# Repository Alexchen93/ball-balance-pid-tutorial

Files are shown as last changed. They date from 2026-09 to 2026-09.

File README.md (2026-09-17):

# Arduino Nano 電腦視覺球平衡控制

這是一套給學生學習「影像辨識、座標轉換、回授控制與 PID」的球平衡平台。Desktop 的 USB 攝影機辨識球的位置，Python 將平台座標傳給 Arduino Nano；Nano 依座標控制兩顆 Servo，讓球回到平台中心。

> **安全第一：** Servo 必須使用獨立、足夠電流的 5–6 V 電源，外部電源 GND 必須與 Nano GND 共地。不要使用 Nano 的 5 V 腳供應 Servo。第一次測試請空載、小角度，並隨時可斷開 Servo 電源。

## 系統架構

```text
USB 攝影機 → OpenCV：球色辨識、接觸點估計、透視校正
                                  ↓ POS / LOST / GEOM / RUN
Desktop ───────────────────── USB Serial ─────────────────→ Arduino Nano
                                                               ↓
                                                     雙軸 PD / 安全限幅
                                                               ↓
                                                       D9、D10 Servo → 平台
```

## 專案內容

| 路徑 | 用途 |
| --- | --- |
| `Camera_Vision/` | Desktop 的 OpenCV 程式、設定與學生操作說明。 |
| `Arduino_Nano_Ball_Balance/` | 正式 Camera PID 韌體與接線／調參說明。 |
| `Arduino_Nano_Ball_Balance_Joystick_Modes/` | **機構校正用**搖桿韌體；不是正式 Camera PID 韌體。 |
| `3d列印檔案/` | 平台、Servo 固定座、鏡頭座等模型（依 `.gitignore` 不上傳）。 |

## 學生先懂這三件事

### 1. 影像像素座標不等於平台控制座標

相機原始影像中：向右是像素 `x` 增加、向下是像素 `y` 增加。因為鏡頭斜拍，平台在畫面裡是梯形；不能直接把像素座標拿去控制 Servo。

按 `C` 依序點 **TL → TR → BR → BL** 後，程式建立 homography（透視校正），把梯形平台轉為正方形控制座標：

| 平台控制座標 | 畫面中的方向 |
| --- | --- |
| `X` 負 → 正 | 左 → 右 |
| `Y` 正 | 平台上方／遠端：TL、TR 的方向 |
| `Y` 負 | 平台下方／近端：BL、BR 的方向 |
| `(0, 0)` | 由四角算出的平台幾何中心 |

所以「影像左右」是 **X 軸**；影像原始向下雖是 `y` 增加，但本專案的控制 `Y` 軸刻意翻轉，讓上方為正、下方為負。

### 2. 綠色圓與橘色 CONTACT 點不同

- **綠色圓**：HSV 找到的球外框與其影像圓心。
- **橘色 `CONTACT` 點**：估計球接觸平台的位置，才是送給 Nano 控制與判斷是否在平台內的點。

斜拍時，球的影像圓心不在平台平面上。程式會依球半徑、平台近端方向，將圓心往接觸方向補償 `0.85 × 半徑`，再做透視轉換。因此請確認**橘色點**而非綠色圓心落在球接觸平台的位置附近。

### 3. PID 在 Nano，不在 Desktop

Camera Vision 只傳送球的位置與安全狀態；正式 Nano 韌體才是 PID、Servo 方向與安全角度的唯一來源。目前起始參數是保守 PD：

```text
X/Y：Kp = 1.25、Ki = 0.00、Kd = 0.12
```

- `P`：球偏離中心越遠，回拉傾斜越大。
- `D`：球快速往外滾時，提早加強煞車。
- `I`：目前保持 0，避免積分造成過衝。

詳見 `Arduino_Nano_Ball_Balance/README.md`。

## 第一次使用流程

### 1. 校正機構並燒錄正式 Nano 韌體

1. 在 Arduino IDE 安裝 `Servo` 函式庫。
2. 先用 `Arduino_Nano_Ball_Balance_Joystick_Modes/` 校正平台水平、Servo 中心與安全端點。
3. 把 `SETC` / `SHOW` 的結果填入正式 `Arduino_Nano_Ball_Balance/Arduino_Nano_Ball_Balance.ino` 的中心與限幅常數。
4. 選擇 **Arduino Nano**（舊板上傳失敗時試 `ATmega328P (Old Bootloader)`），燒錄正式 `.ino`。
5. 使用 Camera Vision 前關閉 Arduino Serial Monitor；它會佔用 Nano 的 serial port。

### 2. 在 Desktop 安裝 Camera Vision

```bash
cd ~/文件/平衡球PID教案/Camera_Vision
python3 -m venv .venv
.venv/bin/python -m pip install --upgrade pip
.venv/bin/python -m pip install -r requirements.txt
```

若顯示 Nano 沒有讀寫權限，將目前 Desktop 使用者加入 serial 群組，登出再登入並重新插拔 Nano：

```bash
sudo usermod -aG dialout "$USER"
```

### 3. 固定鏡頭並完成 B、C

1. 鏡頭固定後，讓四角和整個平台都入鏡；鏡頭或平台移動後一定要重新按 `C`。
2. 執行 `./start_camera_vision.sh`。
3. 選 `2` 可先只測鏡頭，選 `1` 會連接可用 Nano。
4. 按 `B`，點球中心取樣 HSV。綠色圓應穩定包住球。
5. 按 `C`，依序點 TL、TR、BR、BL 四角。成功後，橘色 CONTACT 點用來確認接觸位置。
6. 連上 Nano、球在平台內可辨識時，按 `R` 進 RUN；按 `P` 回 READY，按 `Q` / `Esc` 安全離開。

> 此版本已移除 `D` 零點操作：完成 `C` 時，四角計算出的平台中心自動成為 `(0,0)`。

## PID 學習與測試順序

1. 先空載確認兩軸中心、方向與安全限幅。
2. 放球在中心，單軸小幅偏移測試；若球被推得更遠，立刻按 `P`，再調整對應 `SERVO_X_DIRECTION` 或 `SERVO_Y_DIRECTION`。
3. 若球接近邊緣才來得及回拉，先看 telemetry 的 `tilt`：
   - 已接近 ±20°：機構回拉力／Servo 速度或影像延遲可能不足。
   - 尚未接近最大：可小幅提高 `Kp`，或調整 `Kd` 讓高速外移提早煞車。
4. 若出現高頻抖動，先將 `Kd` 由 `0.12` 降為 `0.08`；不要先增加 `Ki`。

## 文件索引

- [Camera Vision 操作與故障排除](Camera_Vision/README.md)
- [Nano 韌體、接線、PD 參數與 telemetry](Arduino_Nano_Ball_Balance/README.md)
- [搖桿機構校正說明](Arduino_Nano_Ball_Balance_Joystick_Modes/README_Joystick_Discrete_Modes.md)

## 授權

本專案採用 [MIT License](LICENSE)。硬體、Servo 電源與機械結構具有風險；使用者應自行完成安全檢查與測試。

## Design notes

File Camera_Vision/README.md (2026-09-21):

# Camera Vision：Desktop 影像辨識與 Nano 通訊

`ball_vision.py` 在 Desktop 取得 USB 攝影機畫面，以 HSV 追蹤球，將平台座標送到 Arduino Nano。Nano 才負責 PID、Servo 方向、限幅與失聯保護。

## Desktop 一次性設定

```bash
cd ~/文件/平衡球PID教案/Camera_Vision
python3 -m venv .venv
.venv/bin/python -m pip install --upgrade pip
.venv/bin/python -m pip install -r requirements.txt
```

Nano 使用 USB serial。確認裝置與權限：

```bash
python3 -m serial.tools.list_ports -v
ls -l /dev/ttyUSB* /dev/ttyACM* 2>/dev/null
```

常見裝置是 `/dev/ttyUSB0` 或 `/dev/ttyACM0`。若顯示目前使用者無法讀寫，執行下列命令後**登出再登入**，並重新插拔 Nano：

```bash
sudo usermod -aG dialout "$USER"
```

Arduino IDE Serial Monitor、其他 serial monitor 或另一個 Camera Vision 視窗都可能佔用 port；啟動前要關閉它們。

## 啟動方式

```bash
cd ~/文件/平衡球PID教案/Camera_Vision
./start_camera_vision.sh
```

啟動後第一步會顯示攝影機**編號選單**。啟動器會先測試並只列出實際能讀取影像的節點，避免選到 USB 攝影機的中繼資料節點。直接選擇內建或外接 USB 鏡頭的編號即可；不需要輸入 `/dev/video*` 路徑、鏡頭 index 或其他攝影機參數。其後的 READY／RUN、HSV 與平台校正操作均與原本相同。

啟動選單：

| 選項 | 用途 |
| --- | --- |
| `1` | 搜尋一個可讀寫、未被占用的 Nano，連線後進 READY。 |
| `2` | 以 `--no-serial` 只檢查鏡頭與校正；不能 RUN。 |
| `q` | 離開。 |

手動指定 serial port：

```bash
.venv/bin/python ball_vision.py --serial-port /dev/ttyUSB0
```

## 座標與畫面標記

### 相機像素與平台座標

相機像素：右方 `x` 增加、下方 `y` 增加。平台控制座標由 `C` 四角透視校正後產生：

| 控制座標 | 對應畫面方向 |
| --- | --- |
| `X-` / `X+` | 左 / 右 |
| `Y+` | TL、TR 的上方／遠端 |
| `Y-` | BL、BR 的下方／近端 |
| `(0,0)` | 四角算出的平台中心 |

請使用校正後的平台座標判讀，不要直接以斜拍畫面的梯形或像素 `y` 判斷方向。

### 球的位置

- **綠色圓**：HSV 偵測到的球外框；紅點是影像圓心。
- **橘色 `CONTACT` 點**：推估的球與平台接觸點；程式實際傳送給 Nano、檢查是否在邊框內的就是這個點。

球有高度，斜拍時綠色圓心不在平台平面。程式以 `camera_config.json` 的 `detection.contact_offset_radius`（目前 `0.85`）乘球半徑，朝 TL/TR 到 BR/BL 的近端方向補償。如果橘點長期在接觸點上方或下方，再小幅調整此值；不要直接以綠色圓心取代它。

## READY → RUN 操作

| 操作 | 功能 |
| --- | --- |
| `a` | 重新讀取已儲存的 `camera_config.json`。 |
| `b` | 點球中心，取樣 HSV。 |
| `c` | 點 TL → TR → BR → BL 四角；完成後自動把幾何中心設為零點。 |
| `n` | 重新搜尋 Nano。 |
| `p` | 回 READY；停止 live `POS` / `LOST` / Servo 控制。 |
| `r` | Nano 已連線、球可辨識、B/C 完成時進 RUN；RUN 中再按一次回 READY。 |
| `q` / `Esc` | 安全停止並離開。 |
| `Ctrl+C`、停止 `.sh` 程序或 `SIGTERM` | 安全關閉影像視窗、釋放攝影機，並送 Nano 回 `READY`。 |

> 沒有 `D` 操作。C 成功後，平台中心自動是 `(0,0)`。

### 校正順序

1. 固定鏡頭與平台，四角完整入鏡。
2. 按 `B` 點球中心；確認綠色圓穩定包住球。
3. 按 `C`，依序點 TL、TR、BR、BL。錯誤順序、重複、內凹或退化四邊形會被拒絕，上一份有效設定會保留。
4. 確認橘色 CONTACT 點靠近球接觸平台的位置。
5. 連接 Nano，讓球留在平台內，再按 `R`。

`C` 成功後會寫入 `camera_config.json`。鏡頭、平台或解析度改變後必須重新做 `C`。

## 安全與故障排除

- READY 中不會送 `POS`、`LOST` 或 Servo 控制；按 `P` 可隨時回 READY。
- Nano 連續約 300 ms 沒收到新位置或收到 `LOST`，會回中立角。
- `Cannot RUN: Nano is not connected`：按 `n` 搜尋，檢查 USB、權限與 Serial Monitor。
- `Cannot RUN: HSV candidate is outside...`：目前辨識到的候選接觸點不在 C 的平台內。重新做 B / C，或檢查橘色 CONTACT 點補償。
- `ERROR,POSITION_OUT_OF_RANGE`：Nano 拒絕範圍外的位置；確認使用最新版 Camera Vision，並檢查 B、C 和橘色 CONTACT 點。
- 若球被推向更遠方向，立即按 `P`，再調整 Nano 的 `SERVO_X_DIRECTION` 或 `SERVO_Y_DIRECTION`；Camera Vision 不設定 PID。

## 通訊摘要

RUN 前的安全握手：

```text
GEOM,-100,100,-100,100 → GEOM,OK
fresh POS                → POS,OK
final fresh POS + RUN    → STATE,RUN
```

RUN 中，Desktop 傳送 `POS,x_pct,y_pct,timestamp_ms`；找不到球才傳 `LOST`。Nano 韌體不接受 Camera Vision 下發 PID 參數，`PIDX` / `PIDY` 會回 `ERROR,PID_MANAGED_BY_NANO`。

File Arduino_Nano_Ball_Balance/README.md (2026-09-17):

# Arduino Nano：正式 Camera PID 韌體

這個資料夾是正式控制韌體。Desktop 的 `Camera_Vision/ball_vision.py` 只傳送平台座標與安全狀態；Nano 是 PID、Servo 方向、限幅與失聯保護的唯一控制權威。

> `Arduino_Nano_Ball_Balance_Joystick_Modes/` 是校正韌體，不是正式 Camera PID 燒錄目標。

## 接線與安全

| Nano 腳位 | 用途 |
| --- | --- |
| D9 | Servo X 訊號 |
| D10 | Servo Y 訊號 |
| USB | Desktop Serial（115200 baud）與燒錄 |
| GND | 與 Servo 外部電源 GND 共地 |

兩顆 Servo 必須使用獨立、足夠電流的 5–6 V 電源；不得由 Nano 的 5 V 腳供應。

## 燒錄與機構校正

1. Arduino IDE 安裝 `Servo` 函式庫。
2. 先使用搖桿校正韌體找平台水平、Servo 中心與安全端點。
3. 將 `SETC` / `SHOW` 結果填入 `.ino` 頂端的：
   - `SERVO_X_CENTER`
   - `SERVO_Y_CENTER`
   - `SERVO_LIMIT_OFFSET_DEG`
4. 選擇 Arduino Nano 後燒錄；舊 Nano 上傳失敗時選 `ATmega328P (Old Bootloader)`。
5. 先以小角度測試方向。球被推得更遠時，立即停止，修改相對應 `SERVO_X_DIRECTION` 或 `SERVO_Y_DIRECTION` 後重燒。

Arduino Serial Monitor 會佔用 USB serial；使用 Camera Vision 前務必關閉它。

## 控制座標與通訊

Camera Vision 的 `C` 四角將平台映射為百分比座標：

- 左 → 右：`X-` → `X+`
- 平台上方／遠端 TL、TR：`Y+`
- 平台下方／近端 BL、BR：`Y-`
- 平台中心：`(0,0)`

Nano 接收：

```text
GEOM,-100.00,100.00,-100.00,100.00
POS,12.4,-8.7,12345
LOST
RUN
READY
```

安全握手為：

```text
GEOM → GEOM,OK → fresh POS → POS,OK → final fresh POS + RUN → STATE,RUN
```

位置範圍由 `GEOM` 提供。Nano 只接受有界、有限且新鮮的 `POS`；超出範圍會回 `ERROR,POSITION_OUT_OF_RANGE`，找不到球或資料逾時會停止控制並回中立。

Telemetry 每秒約 10 次：

```text
TEL,state,link,x_pct,y_pct,e_x_pct,e_y_pct,u_x_pct,u_y_pct,tilt_x_deg,tilt_y_deg,servo_x,servo_y,age_ms
```

學生觀察邊緣回拉時，特別看：

- `ball`：球的位置。
- `error`：目標中心與球的正規化誤差。
- `output`：PID 輸出百分比。
- `tilt`：要求的平台傾斜角。
- `servo`：實際寫出的 Servo 角度。

若球接近邊緣但 `tilt` 已接近 ±20°，代表可能是 Servo／機構回拉力或影像延遲，而不只是 PID 參數。

## 目前 PD 起始參數

```cpp
DEFAULT_KP_X = 1.25f;
DEFAULT_KI_X = 0.00f;
DEFAULT_KD_X = 0.12f;
DEFAULT_KP_Y = 1.25f;
DEFAULT_KI_Y = 0.00f;
DEFAULT_KD_Y = 0.12f;
```

公式：

```text
error = target - ball
u = Kp × error + Ki × integral(error) + Kd × derivative(error)
tilt = clamp(u, -1, +1) × 20°
```

- `Kp` 提高可讓球還未到邊緣時更早回拉。
- `Kd` 在球快速外移時提供提早煞車；過大會放大影像雜訊、造成抖動。
- `Ki` 現在為 0，因為它無法煞住移動中的球，且容易造成過衝。

若高頻抖動，先將 `Kd` 從 `0.12` 降到 `0.08`；若回拉太慢且沒有明顯抖動，再小幅提高 `Kp`。每次只改一組小幅數值、重新燒錄並記錄結果。不要把 Servo 安全端點當成 PID 調參工具。

## Camera Vision 的責任邊界

Camera Vision 負責 HSV、平台四角與球接觸點估計。它不保存或下發 PID；`PIDX` / `PIDY` 命令會被 Nano 拒絕為 `ERROR,PID_MANAGED_BY_NANO`。任何 PID、Servo 中心、方向或安全端點變更，都必須修改此 `.ino` 後重新燒錄。

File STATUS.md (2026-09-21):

# 平衡球 PID 平台目前狀態

更新日期：2026-09-15

## 已完成且已做程式層驗證

- 正式控制流程由 Nano 韌體掌管 PID；Camera Vision 只在 RUN 前傳送平台幾何資訊與即時位置。
- RUN 握手固定為：`GEOM` → `GEOM,OK` → fresh `POS` → `POS,OK` → final fresh `POS` + `RUN` → `STATE,RUN`。
- 平台範圍由每次四角校正（C）與零點（D）推導，可處理不對稱的零點與平台邊界；Nano 依近、遠邊距離分別正規化 PID 誤差。
- Servo X/Y 各自使用安全中心與安全端點；目前程式中的中心為 X=74°、Y=76°，安全行程為各軸中心 ±20°。

## 2026-09-15 RUN 握手修正

### 問題

Nano 已正確回覆 `GEOM,OK`，但 Python 的 `NanoTransport.poll()` 只把 `ERROR`、`STATE`、`POS,OK` 交給 RUN 狀態機。`GEOM,OK` 因此只顯示在終端，沒有推進 `wait_geom_ack`，造成 RUN 逾時並回到 READY。

### 修正

- `Camera_Vision/ball_vision.py` 現在將 `GEOM,OK` 納入已解析事件。
- `Camera_Vision/tests/test_nano_transport_serial.py` 新增 `GEOM,OK` 回歸測試，防止同類 ACK 再次被僅列印、不交給狀態機。

### 驗證

在 `Camera_Vision/.venv` 執行全部單元測試：**19 tests passed**。

## 尚待實機確認

- 需要重新啟動 Camera Vision，使用已燒錄目前 `Arduino_Nano_Ball_Balance.ino` 的 Nano 做一次受控 RUN 測試。
- 測試前關閉 Arduino Serial Monitor，使用 A 套用已存設定，確認球置於中心；按 R 後預期會看到 `GEOM,OK`、`POS,OK`、`STATE,RUN` 與 `RUN confirmed`。
- 若位置、相機或機構調整，重新執行 C（TL → TR → BR → BL）與 D（零點）後再 RUN。

## 2026-09-21 鏡頭選擇與安全關閉

### 調整

- `Camera_Vision/start_camera_vision.sh` 在既有 Nano 啟動選單前加入攝影機編號選擇；學生不需輸入 `/dev/video*` 路徑或 index。
- 啟動器會先以 OpenCV 讀取一張畫面，只列出可實際擷取影像的節點，略過同一支 UVC 攝影機可能出現的 metadata-only `/dev/video*` 節點。
- 原本 `Camera_Vision/ball_vision.py` 的 HSV 偵測、校正、READY/RUN、Nano 通訊與 PID 分工未改變；只加入 SIGINT/SIGTERM 的收尾處理。
- 按 `q`／`Esc`、`Ctrl+C` 或正常停止 `start_camera_vision.sh` 時，程式會關閉 OpenCV 視窗、釋放攝影機並送 Nano 回 `READY`。`kill -9` 無法進行收尾。

### 2026-09-21 驗證

- `python3 -m py_compile Camera_Vision/ball_vision.py`
- `bash -n Camera_Vision/start_camera_vision.sh`
- 以實際內建鏡頭執行 headless 程式後送出 `SIGTERM`：已確認正常結束且 `/dev/video0` 未殘留占用。
- 在 `Camera_Vision/.venv` 執行 27 個 Python 單元測試與 3 個啟動器／韌體靜態測試，全部通過。

### 實機狀態

- Desktop 的 Logitech C922 曾被偵測到，但在本次最後檢查前已從 USB 斷線；重新接上後，僅在可讀取影像時才會出現在選單中。

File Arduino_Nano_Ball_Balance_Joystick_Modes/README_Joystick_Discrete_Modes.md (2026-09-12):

# Arduino Nano 球平衡平台：搖桿離散硬體校正模式

此版本在原本 Camera/OpenCV/PID 流程外，提供 5-pin 雙軸搖桿的安全機構校正模式。完整專案操作請見根目錄 [`README.md`](../README.md)。

## 接線

| Nano | 搖桿 | 功能 |
| --- | --- | --- |
| A0 | VRx | X 軸類比輸入 |
| A1 | VRy | Y 軸類比輸入 |
| D2 | SW | 按鈕，使用 `INPUT_PULLUP` |
| 5V | VCC / +5V | 搖桿供電 |
| GND | GND | 共地 |

Servo X 使用 D9、Servo Y 使用 D10。Servo 仍須由獨立 5–6 V 電源供應，並與 Nano 共地。

## 開機與 TEST 模式

目前版本會在開機後**自動進入 TEST 模式**，不需要先長按搖桿按鈕。進入後預設為 MODE1。

每一次推桿只接受一個軸的一次動作：

- 搖桿必須回到中立區才會重新 armed。
- 動作間至少保留約 350 ms 的安全間隔。
- 斜推時只接受偏移較大的那個軸，因此不會同時改動 X、Y。
- 持續把搖桿推在同一方向不會連續累加。

## Mode 與按鈕操作

| Mode | 每次搖桿動作 |
| --- | --- |
| MODE1 | 選定軸 ±1° |
| MODE2 | 正方向前往推導後的 MAX；負方向前往推導後的 MIN（目前中心 90、範圍 ±20，為 110° / 70°） |

- **短按 SW**：在 MODE1 / MODE2 之間切換。
- **在 TEST 長按 SW 1.5 秒**：X、Y 回到 `testCenterX` / `testCenterY`。

預設中心是 90°，`SERVO_LIMIT_OFFSET_DEG` 是 20，因此端點由 X 中心 ±20 推導為 70°～110°；調整 offset 可改安全行程，不需要手算端點。

## 建議校正流程

1. 平台空載，確認 Servo 有獨立供電與共地。
2. MODE1 以 1° 單步找平台水平。
3. MODE2 逐一測試 X+/X-/Y+/Y-，確認目前由中心 90、範圍 ±20 推導出的 70°～110° 端點不會卡住；若有風險，縮小 `SERVO_LIMIT_OFFSET_DEG`。
4. 在 115200 baud、Newline 的 Serial Monitor 輸入 `SETC`，再輸入 `SHOW`。
5. 將 `SHOW` 印出的 `SERVO_X_CENTER` / `SERVO_Y_CENTER` / `SERVO_LIMIT_OFFSET_DEG` 寫回 `.ino` 頂端的常數並重新燒錄，才會永久保存。
6. 完成機構校正後，才進行攝影機校正與 PID 控制。

## 常用 Serial 指令

- `STATUS`：顯示 Servo、中心、mode 與 armed 狀態。
- `SHOW`：印出可複製回程式的校正常數。
- `SETC` / `SETCX` / `SETCY`：設定測試中心。
- `CENTER`：回到測試中心。
- `MODE,1` / `MODE,2`：選擇 1° 微調或端點模式。
- `STEP,1`：選擇 1° 微調。
- `X+`、`X-`、`Y+`、`Y-`：手動移動指定軸。
- `X,角度`、`Y,角度`、`XY,X角度,Y角度`：直接指定安全範圍內的角度。
- `JOY`：讀取搖桿 ADC 值；`JOYCAL`：重新校正搖桿中立值。
- `TESTX`、`TESTY`、`TESTBOTH`：執行內建來回機構測試。

## 可調參數

```cpp
constexpr int JOYSTICK_DEADZONE = 100;
constexpr uint16_t JOYSTICK_ACTION_DELAY_MS = 350;
constexpr uint16_t JOYSTICK_LONG_PRESS_MS = 1500;
```

若中立時會誤觸發，增加 `JOYSTICK_DEADZONE`；若每次操作要更慢，增加 `JOYSTICK_ACTION_DELAY_MS`。

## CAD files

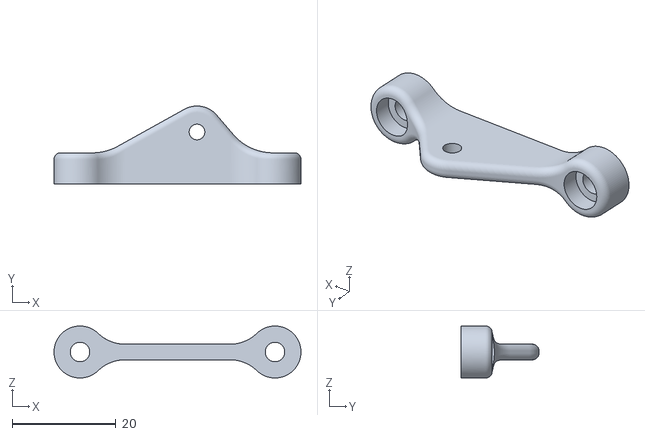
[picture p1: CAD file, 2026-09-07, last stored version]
3d列印檔案/Control Horn v4.stl
47.5 x 15.0 x 10.00

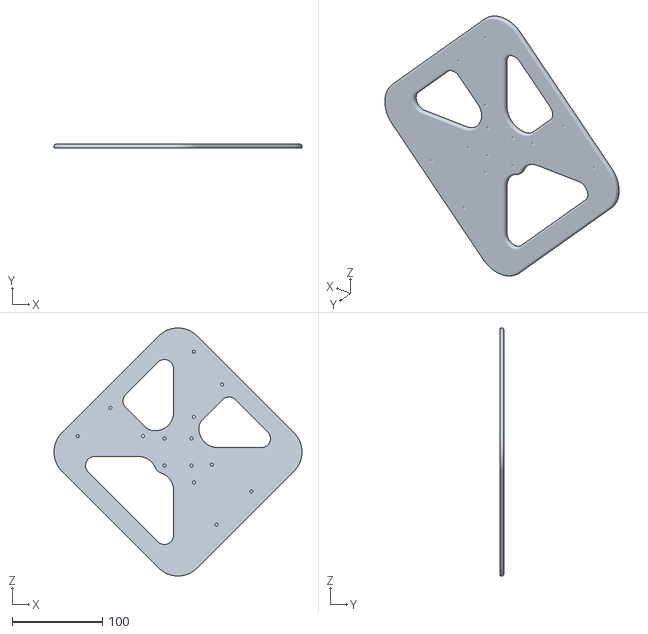
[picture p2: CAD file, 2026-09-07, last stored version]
3d列印檔案/Base v17.stl
275.1 x 4.00 x 275.1

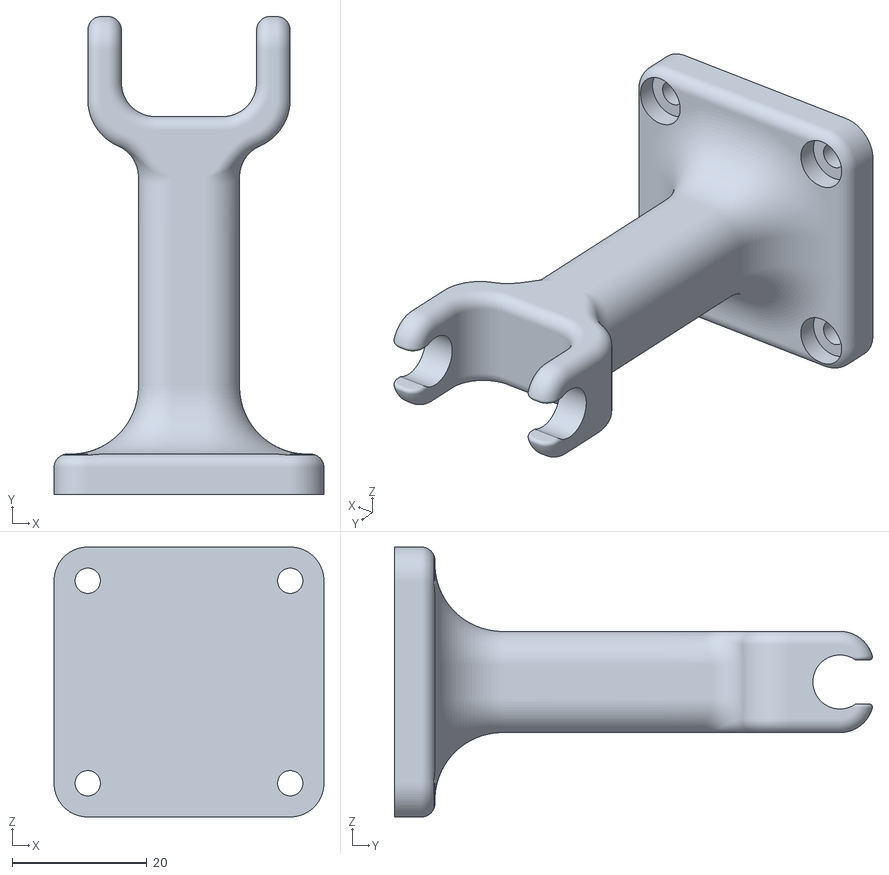
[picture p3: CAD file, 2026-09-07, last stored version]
3d列印檔案/Pivot Post v5.stl
40.0 x 70.8 x 40.0

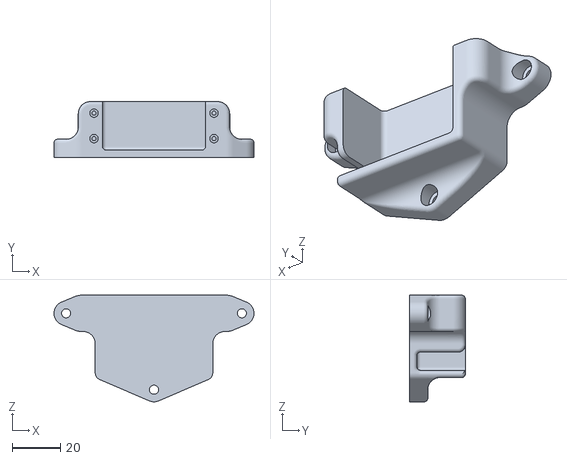
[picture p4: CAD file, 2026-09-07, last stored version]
3d列印檔案/Servo Holder v10.stl
82.5 x 23.0 x 44.0

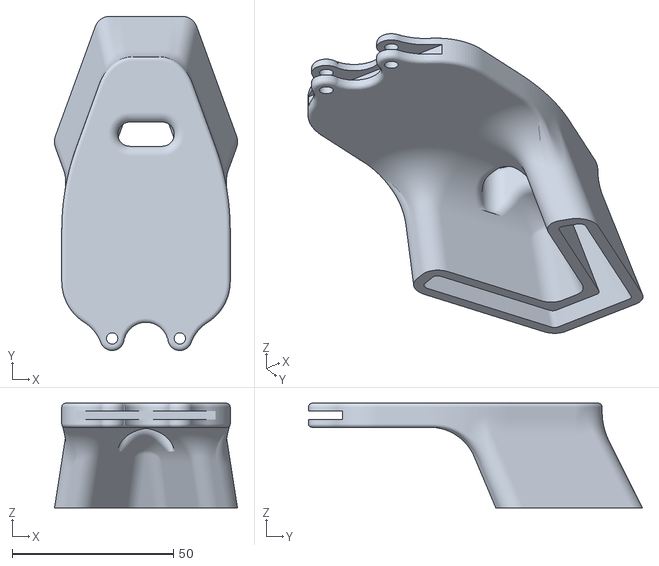
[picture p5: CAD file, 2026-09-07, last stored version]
3d列印檔案/PixyCam Holder v3.stl
56.8 x 103.6 x 32.5

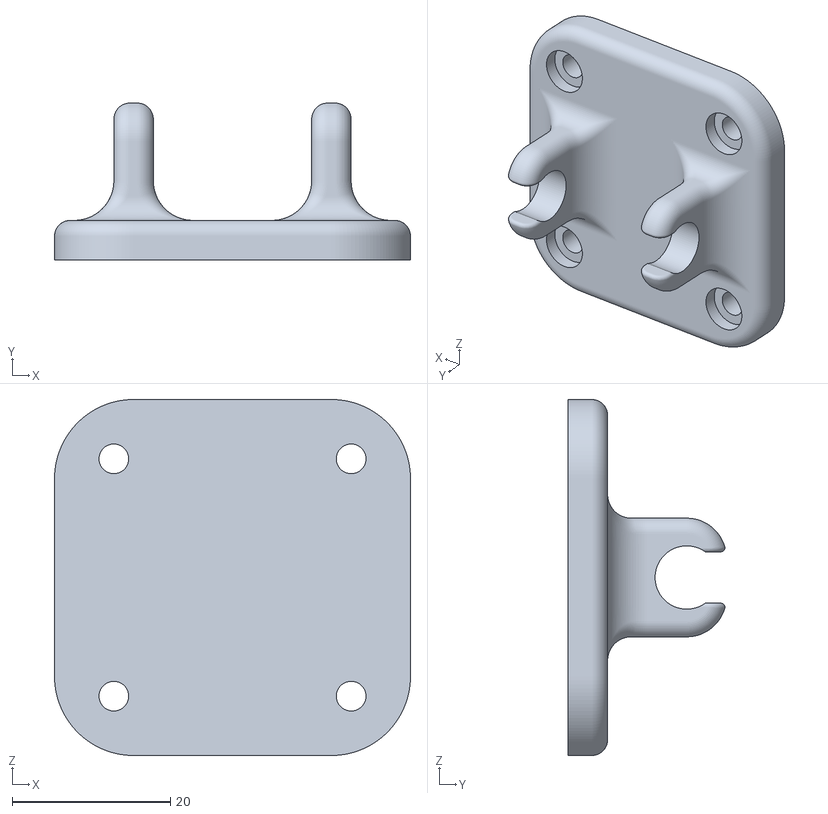
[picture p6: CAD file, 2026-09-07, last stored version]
3d列印檔案/Pivot Pad v5.stl
45.0 x 19.8 x 45.0

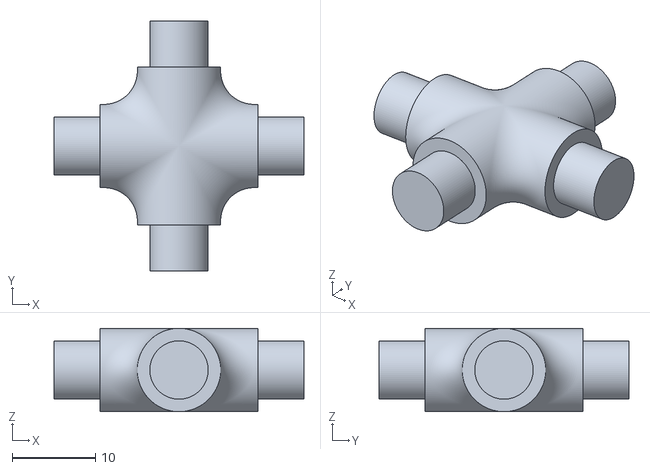
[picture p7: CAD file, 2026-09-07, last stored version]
3d列印檔案/Pivot Cross v3.stl
30.0 x 30.0 x 10.0

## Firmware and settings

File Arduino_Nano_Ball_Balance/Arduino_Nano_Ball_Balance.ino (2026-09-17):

/*
 * Ball-and-Plate controller: PC camera -> USB serial -> Arduino Nano PID
 *
 * PC-to-Nano protocol (ASCII, one command per LF-terminated line):
 *   GEOM,<x_min_pct>,<x_max_pct>,<y_min_pct>,<y_max_pct>
 *   POS,<x_pct>,<y_pct>,<camera_timestamp_ms>
 *   LOST
 *   RUN | READY | TARGET,<x_pct>,<y_pct>
 *   PING | HELP
 *
 * Nano firmware is the only PID parameter source/control authority.
 * PIDX/PIDY commands are rejected with ERROR,PID_MANAGED_BY_NANO.
 *
 * POS replies with POS,OK after the Nano accepts a fresh in-range sample.
 * RUN must be immediately preceded by a fresh accepted POS; READY stops PID and returns servos to neutral.
 * Nano telemetry (10 Hz):
 *   TEL,<state>,<link>,<x_pct>,<y_pct>,<e_x_pct>,<e_y_pct>,<u_x_pct>,<u_y_pct>,<tilt_x_deg>,<tilt_y_deg>,<servo_x>,<servo_y>,<age_ms>
 *
 * Libraries to install from Arduino Library Manager:
 *   Servo
 */

#include <Servo.h>
#include <math.h>
#include <stdlib.h>
#include <string.h>

constexpr uint8_t SERVO_X_PIN = 9;
constexpr uint8_t SERVO_Y_PIN = 10;
constexpr uint8_t STATUS_LED_PIN = LED_BUILTIN;
// ===== 學生校正參數（校正完成後只修改本區） =====
// 來源：校正程式的 SETC / SHOW 結果與學習單紀錄。
// 注意：本次 JOYMOVE / TESTSTAT 觀測到 X=71、Y=76，只代表測試當下的輸出角度，
// 不可當作正式 PID 的機構中心值。正式 PID 請只轉填/調整下列中心與安全行程常數。
// 安全限制：中心應落在各軸 MIN/MAX 之間，端點不可超出校正安全範圍。
// X 軸機構中心角度。校正完成後，從 SETC / SHOW / 學習單轉填；本教案最終中心採 90 度。
constexpr int SERVO_X_CENTER = 74;
// Y 軸機構中心角度。校正完成後，從 SETC / SHOW / 學習單轉填；本教案最終中心採 90 度。
constexpr int SERVO_Y_CENTER = 76;
// Servo 實體安全行程，也是 normalized PID 輸出 100% 時的最大安全機構要求。
// 調整 OFFSET 即可改每軸中心 ±安全端點，不需要手算端點；不要使用實體硬停點。
constexpr int SERVO_LIMIT_OFFSET_DEG = 20;
constexpr int SERVO_X_MIN_ANGLE = SERVO_X_CENTER - SERVO_LIMIT_OFFSET_DEG;
constexpr int SERVO_X_MAX_ANGLE = SERVO_X_CENTER + SERVO_LIMIT_OFFSET_DEG;
constexpr int SERVO_Y_MIN_ANGLE = SERVO_Y_CENTER - SERVO_LIMIT_OFFSET_DEG;
constexpr int SERVO_Y_MAX_ANGLE = SERVO_Y_CENTER + SERVO_LIMIT_OFFSET_DEG;
// ===== 學生校正參數結束 =====

constexpr int SERVO_X_DIRECTION = -1; // 已依左右邊緣實測反轉；若球被推向同側，再改回 1。
constexpr int SERVO_Y_DIRECTION = 1;  // Change to -1 if the Y correction is reversed.

constexpr float MAX_PLATFORM_TILT_X_DEG = SERVO_LIMIT_OFFSET_DEG;
constexpr float MAX_PLATFORM_TILT_Y_DEG = SERVO_LIMIT_OFFSET_DEG;
constexpr float PID_INTEGRAL_LIMIT = 1.0f;
constexpr uint32_t POSITION_TIMEOUT_MS = 300UL;
constexpr uint32_t TELEMETRY_PERIOD_MS = 100UL;
constexpr uint32_t SATURATION_WARNING_MS = 2000UL;
constexpr float POSITION_RANGE_EPSILON_PCT = 0.50f;

// Nano firmware is the single source of truth for PID constants. Camera Vision
// sends only vision/control-state commands and must not override these values.
// PID runs in normalized space: Kp=1.0 means a full-scale position error
// requests 100% of MAX_PLATFORM_TILT_*_DEG; Kp=0.5 would request 50%.
// Initial PD tune for a ball that carries outward momentum near an edge.
// Higher Kp starts the return tilt earlier; small Kd adds speed-proportional
// braking. Keep Ki at zero: it cannot brake a moving ball and can add overshoot.
constexpr float DEFAULT_KP_X = 1.25f;
constexpr float DEFAULT_KI_X = 0.00f;
constexpr float DEFAULT_KD_X = 0.5f;
constexpr float DEFAULT_KP_Y = 1.25f;
constexpr float DEFAULT_KI_Y = 0.00f;
constexpr float DEFAULT_KD_Y = 0.5f;

enum ControllerState : uint8_t { WAIT_LINK, READY, RUN };
enum LinkState : uint8_t { LINK_WAIT, LINK_OK, BALL_LOST, LINK_LOST, POSITION_RANGE_ERROR, GEOMETRY_REQUIRED };

struct PIDController {
  float kp;
  float ki;
  float kd;
  float integral;
  float previousError;
  bool hasPreviousError;

  PIDController(float p, float i, float d)
      : kp(p), ki(i), kd(d), integral(0.0f), previousError(0.0f),
        hasPreviousError(false) {}

  void reset() {
    integral = 0.0f;
    hasPreviousError = false;
  }

  float update(float errorNorm, float dtSeconds) {
    const float derivative = hasPreviousError ? (errorNorm - previousError) / dtSeconds : 0.0f;
    const float candidateIntegral = constrain(
        integral + errorNorm * dtSeconds, -PID_INTEGRAL_LIMIT, PID_INTEGRAL_LIMIT);
    const float unconstrained = kp * errorNorm + ki * candidateIntegral + kd * derivative;
    const float outputNorm = constrain(unconstrained, -1.0f, 1.0f);

    // Conditional integration prevents windup while normalized output is saturated.
    if (outputNorm == unconstrained || errorNorm * outputNorm < 0.0f) {
      integral = candidateIntegral;
    }
    previousError = errorNorm;
    hasPreviousError = true;
    return outputNorm;
  }
};

Servo servoX;
Servo servoY;
PIDController pidX(DEFAULT_KP_X, DEFAULT_KI_X, DEFAULT_KD_X);
PIDController pidY(DEFAULT_KP_Y, DEFAULT_KI_Y, DEFAULT_KD_Y);

ControllerState controllerState = WAIT_LINK;
LinkState linkState = LINK_WAIT;
bool newPositionAvailable = false;
bool servoSaturated = false;
bool geometryConfigured = false;

float ballX = 0.0f;
float ballY = 0.0f;
float targetX = 0.0f;
float targetY = 0.0f;
float positionMinX = 0.0f;
float positionMaxX = 0.0f;
float positionMinY = 0.0f;
float positionMaxY = 0.0f;
float errorNormX = 0.0f;
float errorNormY = 0.0f;
float outputNormX = 0.0f;
float outputNormY = 0.0f;
float requestedTiltX = 0.0f;
float requestedTiltY = 0.0f;
int servoAngleX = SERVO_X_CENTER;
int servoAngleY = SERVO_Y_CENTER;

uint32_t lastPositionMs = 0;
uint32_t lastPidUs = 0;
uint32_t lastTelemetryMs = 0;
uint32_t saturationStartedMs = 0;

char serialLine[96];
uint8_t serialLineLength = 0;

const char *controllerStateName(ControllerState state) {
  switch (state) {
    case WAIT_LINK: return "WAIT";
    case READY: return "READY";
    case RUN: return "RUN";
  }
  return "?";
}

const char *linkStateName(LinkState state) {
  switch (state) {
    case LINK_WAIT: return "WAIT";
    case LINK_OK: return "OK";
    case BALL_LOST: return "BALL";
    case LINK_LOST: return "LOST";
    case POSITION_RANGE_ERROR: return "RANGE";
    case GEOMETRY_REQUIRED: return "GEOM";
  }
  return "?";
}

void writeNeutralServos() {
  // 中心與安全端點統一使用上方「學生校正參數」，不要在其他地方重複硬編碼角度。
  servoAngleX = constrain(SERVO_X_CENTER, SERVO_X_MIN_ANGLE, SERVO_X_MAX_ANGLE);
  servoAngleY = constrain(SERVO_Y_CENTER, SERVO_Y_MIN_ANGLE, SERVO_Y_MAX_ANGLE);
  servoX.write(servoAngleX);
  servoY.write(servoAngleY);
}

void resetControllers() {
  pidX.reset();
  pidY.reset();
  errorNormX = 0.0f;
  errorNormY = 0.0f;
  outputNormX = 0.0f;
  outputNormY = 0.0f;
  requestedTiltX = 0.0f;
  requestedTiltY = 0.0f;
  lastPidUs = 0;
  servoSaturated = false;
  saturationStartedMs = 0;
}

void stopControl(LinkState reason) {
  const bool wasRunning = controllerState == RUN;
  controllerState = (reason == LINK_WAIT) ? WAIT_LINK : READY;
  linkState = reason;
  newPositionAvailable = false;
  resetControllers();
  writeNeutralServos();
  if (wasRunning) {
    Serial.println(F("STATE,READY"));
  }
}

bool positionIsFresh() {
  return linkState == LINK_OK && (uint32_t)(millis() - lastPositionMs) <= POSITION_TIMEOUT_MS;
}

bool positionWithinGeometry(float x, float y) {
  return geometryConfigured && isfinite(x) && isfinite(y) &&
         x >= positionMinX - POSITION_RANGE_EPSILON_PCT &&
         x <= positionMaxX + POSITION_RANGE_EPSILON_PCT &&
         y >= positionMinY - POSITION_RANGE_EPSILON_PCT &&
         y <= positionMaxY + POSITION_RANGE_EPSILON_PCT;
}

bool targetWithinGeometry(float x, float y) {
  return geometryConfigured && isfinite(x) && isfinite(y) &&
         x >= positionMinX && x <= positionMaxX &&
         y >= positionMinY && y <= positionMaxY;
}

bool configureGeometry(float xMin, float xMax, float yMin, float yMax) {
  if (!(xMin < 0.0f && xMax > 0.0f && yMin < 0.0f && yMax > 0.0f)) {
    return false;
  }
  if ((xMax - xMin) < 20.0f || (yMax - yMin) < 20.0f ||
      (xMax - xMin) > 250.0f || (yMax - yMin) > 250.0f) {
    return false;
  }
  positionMinX = xMin;
  positionMaxX = xMax;
  positionMinY = yMin;
  positionMaxY = yMax;
  geometryConfigured = true;
  if (!targetWithinGeometry(targetX, targetY)) {
    targetX = 0.0f;
    targetY = 0.0f;
  }
  return targetWithinGeometry(targetX, targetY);
}

bool parseFloat(const char *text, float &value) {
  if (text == NULL) {
    return false;
  }
  char *end = NULL;
  value = (float)strtod(text, &end);
  return end != text && *end == '\0' && !isnan(value) && !isinf(value);
}

bool parseUnsigned(const char *text, uint32_t &value) {
  if (text == NULL) {
    return false;
  }
  char *end = NULL;
  value = strtoul(text, &end, 10);
  return end != text && *end == '\0';
}

void acceptPosition(float x, float y, uint32_t cameraTimestampMs) {
  (void)cameraTimestampMs;  // Nano uses arrival time for its real PID delta-time.
  if (!geometryConfigured) {
    Serial.println(F("ERROR,GEOM_REQUIRED"));
    stopControl(GEOMETRY_REQUIRED);
    return;
  }
  if (!positionWithinGeometry(x, y)) {
    Serial.println(F("ERROR,POSITION_OUT_OF_RANGE"));
    stopControl(POSITION_RANGE_ERROR);
    return;
  }

  ballX = constrain(x, positionMinX, positionMaxX);
  ballY = constrain(y, positionMinY, positionMaxY);
  lastPositionMs = millis();
  linkState = LINK_OK;
  newPositionAvailable = true;
  if (controllerState == WAIT_LINK) {
    controllerState = READY;
    Serial.println(F("STATE,READY"));
  }
  Serial.println(F("POS,OK"));
}

float normalizedPositionError(float targetPct, float ballPct, float minPct, float maxPct) {
  const float errorPct = targetPct - ballPct;
  const float denominator = errorPct >= 0.0f ? targetPct - minPct : maxPct - targetPct;
  if (denominator <= 0.0f) {
    return 0.0f;
  }
  return constrain(errorPct / denominator, -1.0f, 1.0f);
}

void updateServos() {
  // Platform tilt requests come from normalized PID output; servo endpoints are separate physical safety bounds.
  const float requestedX = SERVO_X_CENTER + SERVO_X_DIRECTION * requestedTiltX;
  const float requestedY = SERVO_Y_CENTER + SERVO_Y_DIRECTION * requestedTiltY;
  servoAngleX = constrain((int)round(requestedX), SERVO_X_MIN_ANGLE, SERVO_X_MAX_ANGLE);
  servoAngleY = constrain((int)round(requestedY), SERVO_Y_MIN_ANGLE, SERVO_Y_MAX_ANGLE);
  servoX.write(servoAngleX);
  servoY.write(servoAngleY);

  servoSaturated = servoAngleX == SERVO_X_MIN_ANGLE || servoAngleX == SERVO_X_MAX_ANGLE ||
                    servoAngleY == SERVO_Y_MIN_ANGLE || servoAngleY == SERVO_Y_MAX_ANGLE;
  if (servoSaturated && saturationStartedMs == 0) {
    saturationStartedMs = millis();
  }
  if (!servoSaturated) {
    saturationStartedMs = 0;
  }
}

void updatePidForPosition() {
  if (!newPositionAvailable || controllerState != RUN) {
    return;
  }
  newPositionAvailable = false;
  const uint32_t nowUs = micros();
  const float dtSeconds = lastPidUs == 0
                              ? 0.033f
                              : constrain((nowUs - lastPidUs) / 1000000.0f, 0.010f, 0.150f);
  lastPidUs = nowUs;
  errorNormX = normalizedPositionError(targetX, ballX, positionMinX, positionMaxX);
  errorNormY = normalizedPositionError(targetY, ballY, positionMinY, positionMaxY);
  outputNormX = pidX.update(errorNormX, dtSeconds);
  outputNormY = pidY.update(errorNormY, dtSeconds);
  requestedTiltX = outputNormX * MAX_PLATFORM_TILT_X_DEG;
  requestedTiltY = outputNormY * MAX_PLATFORM_TILT_Y_DEG;
  updateServos();
}

void checkSafetyTimeout() {
  if (linkState == LINK_OK && !positionIsFresh()) {
    stopControl(LINK_LOST);
  }
}

void printTelemetry() {
  const uint32_t ageMs = positionIsFresh() ? millis() - lastPositionMs : 9999UL;
  Serial.print(F("TEL,"));
  Serial.print(controllerStateName(controllerState));
  Serial.print(','); Serial.print(linkStateName(linkState));
  Serial.print(','); Serial.print(ballX, 1);
  Serial.print(','); Serial.print(ballY, 1);
  Serial.print(','); Serial.print(errorNormX * 100.0f, 1);
  Serial.print(','); Serial.print(errorNormY * 100.0f, 1);
  Serial.print(','); Serial.print(outputNormX * 100.0f, 1);
  Serial.print(','); Serial.print(outputNormY * 100.0f, 1);
  Serial.print(','); Serial.print(requestedTiltX, 2);
  Serial.print(','); Serial.print(requestedTiltY, 2);
  Serial.print(','); Serial.print(servoAngleX);
  Serial.print(','); Serial.print(servoAngleY);
  Serial.print(','); Serial.println(ageMs);
}


void updateStatusLed() {
  if (controllerState == RUN) {
    digitalWrite(STATUS_LED_PIN, (millis() / 500UL) % 2U);
  } else if (linkState == LINK_OK) {
    digitalWrite(STATUS_LED_PIN, HIGH);
  } else {
    digitalWrite(STATUS_LED_PIN, LOW);
  }
}

void printHelp() {
  Serial.println(F("PC protocol: GEOM,xmin_pct,xmax_pct,ymin_pct,ymax_pct -> GEOM,OK before POS/RUN"));
  Serial.println(F("POS,x_pct,y_pct,timestamp -> POS,OK | final POS immediately before RUN | LOST | READY"));
  Serial.println(F("TARGET,x,y | PING | HELP"));
  Serial.println(F("PID source: Nano firmware only; PIDX/PIDY return ERROR,PID_MANAGED_BY_NANO"));
}

void processCommand(char *line) {
  char *command = strtok(line, ",");
  if (command == NULL) {
    return;
  }

  if (strcmp(command, "GEOM") == 0) {
    float xMin, xMax, yMin, yMax;
    if (parseFloat(strtok(NULL, ","), xMin) && parseFloat(strtok(NULL, ","), xMax) &&
        parseFloat(strtok(NULL, ","), yMin) && parseFloat(strtok(NULL, ","), yMax) &&
        strtok(NULL, ",") == NULL && controllerState != RUN && configureGeometry(xMin, xMax, yMin, yMax)) {
      stopControl(positionIsFresh() ? LINK_OK : LINK_WAIT);
      Serial.println(F("GEOM,OK"));
    } else {
      geometryConfigured = false;
      Serial.println(F("ERROR,BAD_GEOM"));
      stopControl(GEOMETRY_REQUIRED);
    }
  } else if (strcmp(command, "POS") == 0) {
    float x, y;
    uint32_t timestamp;
    if (parseFloat(strtok(NULL, ","), x) && parseFloat(strtok(NULL, ","), y) &&
        parseUnsigned(strtok(NULL, ","), timestamp) && strtok(NULL, ",") == NULL) {
      acceptPosition(x, y, timestamp);
    } else {
      Serial.println(F("ERROR,BAD_POS"));
    }
  } else if (strcmp(command, "LOST") == 0 && strtok(NULL, ",") == NULL) {
    stopControl(BALL_LOST);
  } else if (strcmp(command, "RUN") == 0 && strtok(NULL, ",") == NULL) {
    if (!geometryConfigured) {
      Serial.println(F("ERROR,GEOM_REQUIRED"));
      stopControl(GEOMETRY_REQUIRED);
    } else if (positionIsFresh()) {
      controllerState = RUN;
      resetControllers();
      Serial.println(F("STATE,RUN"));
    } else {
      Serial.println(F("ERROR,FRESH_POSITION_REQUIRED"));
    }
  } else if (strcmp(command, "READY") == 0 && strtok(NULL, ",") == NULL) {
    stopControl(positionIsFresh() ? LINK_OK : LINK_WAIT);
    Serial.print(F("STATE,"));
    Serial.println(controllerStateName(controllerState));
  } else if (strcmp(command, "TARGET") == 0) {
    float x, y;
    if (parseFloat(strtok(NULL, ","), x) && parseFloat(strtok(NULL, ","), y) &&
        strtok(NULL, ",") == NULL && targetWithinGeometry(x, y)) {
      targetX = x;
      targetY = y;
      Serial.println(F("TARGET,OK"));
    } else {
      Serial.println(F("ERROR,BAD_TARGET"));
    }
  } else if (strcmp(command, "PIDX") == 0 || strcmp(command, "PIDY") == 0) {
    Serial.println(F("ERROR,PID_MANAGED_BY_NANO"));
  } else if (strcmp(command, "PING") == 0 && strtok(NULL, ",") == NULL) {
    Serial.println(F("PONG"));
  } else if (strcmp(command, "HELP") == 0 && strtok(NULL, ",") == NULL) {
    printHelp();
  } else {
    Serial.println(F("ERROR,UNKNOWN_COMMAND"));
  }
}

void readSerialCommands() {
  while (Serial.available() > 0) {
    const char incoming = (char)Serial.read();
    if (incoming == '\r') {
      continue;
    }
    if (incoming == '\n') {
      serialLine[serialLineLength] = '\0';
      processCommand(serialLine);
      serialLineLength = 0;
    } else if (serialLineLength < sizeof(serialLine) - 1) {
      serialLine[serialLineLength++] = incoming;
    } else {
      serialLineLength = 0;
      Serial.println(F("ERROR,LINE_TOO_LONG"));
    }
  }
}

void setup() {
  pinMode(STATUS_LED_PIN, OUTPUT);
  digitalWrite(STATUS_LED_PIN, LOW);
  Serial.begin(115200);
  servoX.attach(SERVO_X_PIN);
  servoY.attach(SERVO_Y_PIN);
  writeNeutralServos();
  Serial.println(F("BALL_CTRL,PC_VISION_MODE"));
  printHelp();
}

void loop() {
  readSerialCommands();
  checkSafetyTimeout();
  updatePidForPosition();

  const uint32_t nowMs = millis();
  if ((uint32_t)(nowMs - lastTelemetryMs) >= TELEMETRY_PERIOD_MS) {
    lastTelemetryMs = nowMs;
    printTelemetry();
  }
  updateStatusLed();
}

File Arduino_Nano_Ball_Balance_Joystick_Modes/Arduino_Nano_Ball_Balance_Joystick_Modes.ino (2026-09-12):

/*
 * Ball-and-Plate controller: PC camera -> USB serial -> Arduino Nano PID
 *
 * PC-to-Nano protocol (ASCII, one command per LF-terminated line):
 *   POS,<x_mm>,<y_mm>,<camera_timestamp_ms>
 *   LOST
 *   RUN | READY | TARGET,<x_mm>,<y_mm>
 *   PIDX,<kp>,<ki>,<kd> | PIDY,<kp>,<ki>,<kd> | PING
 *
 * Nano telemetry (10 Hz):
 *   TEL,<state>,<link>,<x>,<y>,<error_x>,<error_y>,<u_x>,<u_y>,<servo_x>,<servo_y>,<age_ms>
 *
 * Hardware TEST extension: 5-pin analog joystick on A0/A1/D2.
 * Hold joystick SW for 1.5 s in WAIT/READY to enter TEST without a PC.
 * In TEST, each joystick deflection triggers exactly ONE movement. The stick
 * must return to center before another movement is accepted. Short-press SW
 * toggles MODE 1 = MICRO STEP (1 degree) and MODE 2 = ENDPOINT. In ENDPOINT
 * mode a single deflection drives the selected X or Y axis directly to
 * MIN/MAX. Long-press SW in TEST returns both axes to the mechanical center.
 *
 * Libraries to install from Arduino Library Manager:
 *   Servo
 */

#include <Servo.h>
#include <math.h>
#include <stdlib.h>
#include <string.h>

constexpr uint8_t SERVO_X_PIN = 9;
constexpr uint8_t SERVO_Y_PIN = 10;
constexpr uint8_t STATUS_LED_PIN = LED_BUILTIN;

// 5-pin analog joystick module (KY-023 / PS2-style): GND, +5V, VRx, VRy, SW.
constexpr uint8_t JOYSTICK_X_PIN = A0;
constexpr uint8_t JOYSTICK_Y_PIN = A1;
constexpr uint8_t JOYSTICK_SW_PIN = 2;
constexpr int JOYSTICK_X_DIRECTION = 1;
constexpr int JOYSTICK_Y_DIRECTION = 1;
constexpr int JOYSTICK_DEADZONE = 100;
constexpr uint16_t JOYSTICK_ACTION_DELAY_MS = 350;  // Minimum time between accepted moves.
constexpr uint16_t JOYSTICK_LONG_PRESS_MS = 1500;
constexpr uint16_t JOYSTICK_DEBOUNCE_MS = 30;

// ===== 學生校正參數（校正完成後只修改本區） =====
// Mechanical calibration: set these before enabling RUN on the real platform.
constexpr int SERVO_X_CENTER = 71;
constexpr int SERVO_Y_CENTER = 76;
// X 中心左右可移動的安全範圍。目前端點是 X中心90 ±20，推導為 70～110 度；
// 調整 OFFSET 即可改安全行程，不需要手算端點。
// 若未來 X/Y 中心分開，須確認共用範圍仍適用，避免暗中改變 PID 行為。
constexpr int SERVO_LIMIT_OFFSET_DEG = 20;
constexpr int SERVO_MIN_ANGLE = SERVO_X_CENTER - SERVO_LIMIT_OFFSET_DEG;
constexpr int SERVO_MAX_ANGLE = SERVO_X_CENTER + SERVO_LIMIT_OFFSET_DEG;
// ===== 學生校正參數結束 =====
constexpr int SERVO_X_DIRECTION = 1;  // Change to -1 if the X correction is reversed.
constexpr int SERVO_Y_DIRECTION = 1;  // Change to -1 if the Y correction is reversed.

constexpr float POSITION_LIMIT_MM = 150.0f;
constexpr float PID_OUTPUT_LIMIT_DEG = 8.0f;
constexpr float PID_INTEGRAL_LIMIT = 60.0f;
constexpr uint32_t POSITION_TIMEOUT_MS = 300UL;
constexpr uint32_t TELEMETRY_PERIOD_MS = 100UL;
// Serial Monitor quiet by default. TELON/TELOFF can change this at runtime.
bool autoTelemetryEnabled = false;
constexpr uint32_t SATURATION_WARNING_MS = 2000UL;

// Conservative first-power-on values. Tune X and Y independently on hardware.
constexpr float DEFAULT_KP_X = 0.10f;
constexpr float DEFAULT_KI_X = 0.00f;
constexpr float DEFAULT_KD_X = 0.25f;
constexpr float DEFAULT_KP_Y = 0.10f;
constexpr float DEFAULT_KI_Y = 0.00f;
constexpr float DEFAULT_KD_Y = 0.25f;

enum ControllerState : uint8_t { WAIT_LINK, READY, RUN, TEST };
enum LinkState : uint8_t { LINK_WAIT, LINK_OK, BALL_LOST, LINK_LOST, POSITION_RANGE_ERROR };
enum TestMoveMode : uint8_t { TEST_MICRO_STEP, TEST_ENDPOINT };

struct PIDController {
  float kp;
  float ki;
  float kd;
  float integral;
  float previousMeasurement;
  bool hasPreviousMeasurement;

  PIDController(float p, float i, float d)
      : kp(p), ki(i), kd(d), integral(0.0f), previousMeasurement(0.0f),
        hasPreviousMeasurement(false) {}

  void reset() {
    integral = 0.0f;
    hasPreviousMeasurement = false;
  }

  float update(float target, float measurement, float dtSeconds) {
    const float error = target - measurement;
    const float derivative = hasPreviousMeasurement
                                 ? -(measurement - previousMeasurement) / dtSeconds
                                 : 0.0f;
    const float candidateIntegral = constrain(
        integral + error * dtSeconds, -PID_INTEGRAL_LIMIT, PID_INTEGRAL_LIMIT);
    const float unconstrained = kp * error + ki * candidateIntegral + kd * derivative;
    const float output = constrain(unconstrained, -PID_OUTPUT_LIMIT_DEG, PID_OUTPUT_LIMIT_DEG);

    // Conditional integration prevents windup while an output is angle-limited.
    if (output == unconstrained || error * output < 0.0f) {
      integral = candidateIntegral;
    }
    previousMeasurement = measurement;
    hasPreviousMeasurement = true;
    return output;
  }
};

Servo servoX;
Servo servoY;
PIDController pidX(DEFAULT_KP_X, DEFAULT_KI_X, DEFAULT_KD_X);
PIDController pidY(DEFAULT_KP_Y, DEFAULT_KI_Y, DEFAULT_KD_Y);

ControllerState controllerState = WAIT_LINK;
LinkState linkState = LINK_WAIT;
bool newPositionAvailable = false;
bool servoSaturated = false;

float ballX = 0.0f;
float ballY = 0.0f;
float targetX = 0.0f;
float targetY = 0.0f;
float errorX = 0.0f;
float errorY = 0.0f;
float outputX = 0.0f;
float outputY = 0.0f;
int servoAngleX = SERVO_X_CENTER;
int servoAngleY = SERVO_Y_CENTER;

uint32_t lastPositionMs = 0;
uint32_t lastPidUs = 0;
uint32_t lastTelemetryMs = 0;
uint32_t saturationStartedMs = 0;

int joystickCenterX = 512;
int joystickCenterY = 512;
int joystickRawX = 512;
int joystickRawY = 512;
uint32_t lastJoystickMoveMs = 0;
bool joystickMoveArmed = true;
bool joystickStablePressed = false;
bool joystickLastRawPressed = false;
bool joystickLongHandled = false;
uint32_t joystickDebounceChangedMs = 0;
uint32_t joystickPressStartedMs = 0;

// Manual hardware-test calibration values. These are RAM-only candidates;
// use SHOW to print the constants that should be copied into the production
// calibration section after the platform is mechanically level.
int testCenterX = SERVO_X_CENTER;
int testCenterY = SERVO_Y_CENTER;
TestMoveMode testMoveMode = TEST_MICRO_STEP;
constexpr int TEST_MICRO_STEP_DEG = 1;
constexpr int TEST_OFFSET_DEG = 3;
constexpr uint16_t TEST_HOLD_MS = 700;
constexpr uint16_t TEST_RETURN_MS = 500;

char serialLine[96];
uint8_t serialLineLength = 0;

const char *controllerStateName(ControllerState state) {
  switch (state) {
    case WAIT_LINK: return "WAIT";
    case READY: return "READY";
    case RUN: return "RUN";
    case TEST: return "TEST";
  }
  return "?";
}

const char *linkStateName(LinkState state) {
  switch (state) {
    case LINK_WAIT: return "WAIT";
    case LINK_OK: return "OK";
    case BALL_LOST: return "BALL";
    case LINK_LOST: return "LOST";
    case POSITION_RANGE_ERROR: return "RANGE";
  }
  return "?";
}


void resetControllers();
bool positionIsFresh();
const char *controllerStateName(ControllerState state);
void printTestStatus();
void enterTestMode();
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

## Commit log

2026-09-07 Initial release: computer vision ball balancing system
    [Base v17.stl, Control Horn v4.stl, Pivot Cross v3.stl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]
2026-09-07 Ignore local reference and 3D print files
    [Base v17.stl, Control Horn v4.stl, Pivot Cross v3.stl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]
2026-09-09 docs: add joystick calibration guide
2026-09-11 Remove OLED from calibration and PID firmware
2026-09-11 Add updated PID lesson and calibration worksheet
2026-09-12 Remove OLED remnants and update camera READY flow
2026-09-12 Fix RUN handshake fresh POS race
    [Arduino_Nano_Ball_Balance.ino, ball_vision.py]
2026-09-12 Fix POS acknowledgement compatibility
    [Arduino_Nano_Ball_Balance.ino, ball_vision.py]
2026-09-12 Record camera calibration status
2026-09-13 Stage P-only PID diagnostic
2026-09-13 Align Nano fallback PID with P-only profile
2026-09-13 Make Nano sole PID authority
2026-09-13 Implement normalized Nano PID tilt mapping
2026-09-15 fix: harden camera PID startup workflow
    [ball_vision.py, test_corner_geometry.py, test_nano_transport_serial.py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]
2026-09-15 fix: complete geometry-aware RUN handshake
    [Arduino_Nano_Ball_Balance.ino, ball_vision.py, test_corner_geometry.py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]
2026-09-17 docs: add student camera setup and control concepts
2026-09-21 feat: add safe camera selection and shutdown
2026-11-04 Update joystick calibration and status output
2026-11-05 Add joystick maze control and calibration updates
2026-11-10 Add independent servo limits and improve vision tracking
2026-11-11 Synchronize servo centers and camera calibration
2026-11-11 新增 Windows 啟動器與繁體中文操作介面
2026-11-11 Add Windows camera and Nano selection
2026-11-11 Fix PowerShell Python runtime validation
2026-11-11 Clarify camera preview and preserve calibration workflow
